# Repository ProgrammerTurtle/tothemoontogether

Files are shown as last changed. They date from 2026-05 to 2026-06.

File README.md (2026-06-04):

# To The Moon Together

## Overview

fulluptmtt1

To The Moon Together, or TTMT, is a 6 foot tall, 3” diameter, N-Class sub minimum diameter amateur sounding rocket - meaning a rocket carrying scientific payloads. N-Class being the motor class, and sub minimum diameter meaning that the motor casing is the main structure of the rocket - no additional body tube around it. This allows for very high performance - aiming for mach 3 and an altitude of 62 thousand feet (19KM).

Current Planned Launch: BALLS 34 in the Black Rock Desert, September 2026. 

## Flight Avionics

TTMT will be flying a MetrumITX and Featherweight Blue Jay inside of the nose cone avionics bay. These two computers are responsible for parachute deployment and flight logging. 

## Payload

The payload features a three-board distributed instrumentation avionics stack using a CAN-FD bus — each board carries its own STM32G0B1CCU6 MCU, enabling redundant cross-validation and independent experiment processing



**Experiment 1** is a Geiger counter: An SBM 21 geiger tube resides at the bottom of the payload for monitoring cosmis ray flux. At 62kft, the rocket should be nearing the Regener-Pfotzer maximum point of cosmic flux.

**Experiment 2** is atmospheric charge measurement: By referencing between the nose tip and rocket body, across the insulating fiberglass, atmospheric gathered static charge can theoretically be monitored during flight.

**Experiment 3** is an attempt to measure air density, and thus altitude, through structure resonance: By utilizing a piezo transducer embedded in the airframe, sine sweeps can be ran on the head end structure during descent. By monitoring resonance response, air density can hopefully be determined. From air density, altitude can be derived. 

To top it all off, there is a Runcam Split 4 v2 camera mounted in a custom shroud and heatsink unit to record footage of the entire flight. Provided the flight is completely nominal, footage of everything from launch to touchdown should be captured. 

That's right, a total of 4 fully custom PCBs. 

fullupttmt2

---

BOM is visible here: https://docs.google.com/spreadsheets/d/1I6cnVDX1UCcmCTm6yOHvnUr30Lxsm3f6hqrUW3u3K9U/edit?usp=sharing
Or attached as a .CSV

## Why am I building this?

For a long time, I have had a passion for rocketry. I started off doing model rockets with my dad and it eventually grew into an obsession with high power rocketry. Whether it's developing machines for producing rocket parts (like a carbon fiber tube winder that I am using for my fin can tube) or actual rockets, I have spent hundreds, if not thousands of hours working on this hobby.
I got an opportunity to do a really high performance build. I was making a camera module for a 3" rocket for a friend and realized - hey, why don't I make a rocket for this camera module too? After all, I have to get a minimum of 2 pcbs assembled per design.
This is that rocket. I have poured so many hours into this, I have almost failed classes over this, I have lost sleep over this. Making it into a scientific platform allows me to merge my passions in rocketry, physics, math, and general science in a way I haven't been able to before.
So. Godspeed!

## PCB Photos and Wiring Diagrams

<details>
  <summary>Click to Expand</summary>

## PCB Photos

### Camera PCB



---

### Instrumentation MCU PCB



---

### Instrumentation Sensor PCB



---

### Instrumentation Geiger PCB



---

### Instrumentation Flex PCB Cables




---

## Wiring Diagrams

### Nosecone AV Bay Wiring


---

### Payload Wiring


</details>

## Zine Page



## This project was made possible by:
- Hackclub: Fallout
- Sunlu 
- And many friends within the amateur rocketry community

## BOM

| Item | Quantity | Cost | Source | Purpose | |
|---|---|---|---|---|---|
| STRUCTURE | | | | | |
| 3" Light Fiberglass Sleeve 20FT | | 1 | $20.00 | https://sollercompositesllc.com/product/natural-uncolored-3in-light-fiberglass-sleeves/ | Nose cone and chute cannon layups |
| Aeropoxy Quart Kit | 1 | $110.00 | https://www.aircraftspruce.com/catalog/pnpages/01-42135.php? | Nose Cone, Chute Cannon, and Fin Can layups | |
| ELECTRONICS | | | | | |
| STLink USB Debugger | 1 | $3.00 | https://www.aliexpress.us/item/3256807639661526.html? | Debugging and Programming Boards | |
| Wio Tracker L1 Pro | 1 | $48.00 | https://www.seeedstudio.com/Wio-Tracker-L1-Pro-p-6454.html | Base Station for Camera Board - Non-custom for Reliability Purposes | |
| LSM6DSO32TR Accelerometer | 1 | $12.00 | https://www.aliexpress.us/item/3256811581419858.html? | Accelerometer - Resonant Response Experiment | |
| MetrumITX Board + Ground Station | 1 | $240.00 | Kev1n8088 on Slack | Tracking, Flight Control | |
| Elvin Beacon | 1 | N/A | Already Owned | Tracking | |
| Reperix Tracker | 1 | N/A | Already Owned | Tracking | |
| Runcam Split 4 V2 Camera | 1 | $90.00 | https://www.aliexpress.us/item/3256808492130639.html? | Recording the awesome flight | |
| 1s 300mah Lipo Battery | 14 | $22.00 | https://www.aliexpress.us/item/3256811737992102.html? | Powering everything - one 1s4p pack + one 1s3p pack + 4 standalone cells + 4 redundant cells | |
| RECOVERY | | | | | |
| Ematches, Firewire MJG | 20 | $20.00 | https://www.csrocketry.com/recovery-supplies/ejection-supplies/firewire-electric-match.html | Recovery Charge Firing | |
| Custom Drogue and Main Parachute | 2 | $140.00 | Parachute Friend | Recovering the rocket - landing | |
| 3/8"" Flat Kevlar | 1 | N/A | Already Owned | Attaching Parachutes to Rocket - Shock Cord | |
| MOTOR | | | | | |
| "3"" Aluminum Tube 6FT | | 1 | $145.00 | https://www.dxengineering.com/parts/dxe-at1317 | Motor Casing Stock, will be cut and drilled to size by Me.  |
| Nozzle Assembly - Aluminum, Phenolic, Graphite  | 1 | $230.00 | Local Machinist | For Motor Nozzle | |
| HARDWARE | | | | | |
| McMaster-Carr Shipping and Tax | 1 | $30.00 | https://www.mcmaster.com | Shipping and Tax | |
| 6-32 1/2" Countersunk Torx Bolt | 10 | $13.00 | https://www.mcmaster.com/90920A148/ | Payload Mounting | |
| 1/4-20 Eye Hanger Bolt | 1 | $18.00 | https://www.mcmaster.com/90172A542/ | Recovery Anchor | |
| M2 Countersunk Torx Screws, M5 | 20 | $8.00 | https://www.mcmaster.com/90236A103/ | Camera Mounting | |
| 2-56 Low Profile Nut | 10 | $5.00 | https://www.mcmaster.com/90730A003/ | Payload Assembly | |
| 2-56 Threaded Rod, 1ft | 1 | $4.00 | https://www.mcmaster.com/90034A460/ | Payload Assembly | |
| 3mm Dowel Pins, 8mm Long | 10 | $10.00 | https://www.mcmaster.com/93600A303/ | Chute Cannon Attachment | |
| 3-48 Socket Head Screws 1/2" Long  | 10 | $6.00 | https://www.mcmaster.com/92185A098/ | Internal Coupler Assembly |
| 3-48 Socket Head Screws 1/4" Long  | 10 | $5.00 | https://www.mcmaster.com/92185A096/ | Internal Coupler Assembly |
|2-56 Button Head Hex Screws  5/16" Long | 20 | $7.00 | https://www.mcmaster.com/92949A078/ | Payload Assemby |
| 1/4' Diameter 5/16" Long Steel Dowel Pins | 20 | $22.00 | https://www.mcmaster.com/98381A535/ | Forward Motor Assembly | |
| 1/4-20 Set Screws, Flat Tip,3/8 | 25 | $7.50 | https://www.mcmaster.com/94355A535/ | Aft Motor Assembly | |
|6-32 Button Head Hex Screw 5/16" | 16 | $5.00 | https://www.mcmaster.com/92949A145/ | Radax Assemblies |
| MISCELLANEOUS | | | | | |
| Purple Mica Pigment | 1 | $14.00 | https://a.co/d/01c2ZzY7 | Coloring Nonmetallic Parts/Accents | |
| Partall Mold Release Wax | 1 | $17.00 | https://a.co/d/0fLlNBUW | Mold Release for Fiberglass/CF part molds. | |
| 915mhz LORA Antenna | 4 | $6.00 | https://www.aliexpress.us/item/3256805050972049.html? | Payload Board Antennas | |
| 500C Thermistor ` | 1 | $10.00 | https://www.aliexpress.us/item/2255800405055939.html? | Nose Tip Temperature Measurements | |
| PCBWay Non-Sponsored Cost | 1 | $25.00 | pcbway.com | PCBWay only offered a fixed amount. | |
| JLCCNC Misc. Cost for Custom PCBS And CNC Parts | 1 | $460.00 | jlccnc.com, fedex.com | OSHWLAB Stars only covers 80% of project cost, so there is a small cost applicable. Shipping through FedEx aswell. | |
| 20mm Piezo Transducer | 1 | $2.00 | https://www.aliexpress.us/item/3256812072131171.html? | Payload Experiment - Resonant Response | |
| SBM-21 Geiger Tube | 1 | $36.00 | https://www.ebay.com/itm/388693213334? | Payload Experiment - Radiation | |
| MMCX RG316 Coax Cable, 10CM | 1 | $3.00 | https://a.aliexpress.com/_mt1c4Fz | Payload Experiment - Atmospheric Charge | |
| MMCX Female to SMA cable , 30cm | 1 | $3.00 | https://a.aliexpress.com/_mL6sZkL | Payload Experiment - Atmospheric Charge | |
| MMCX-KWE Female Right Angle Board Connector | 1 | $3.00 | https://www.aliexpress.us/item/3256807429972438.html? | Payload Experiment - Atmospheric Charge | |
| | | | | | |
| GRAND TOTAL | | $1,799.50 | | | |

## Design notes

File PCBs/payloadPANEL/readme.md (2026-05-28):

This is a panelized form of the three payload PCBs for the purpose of saving money when ordering. Saves almost $100 from JLCPCB! 

No Schematic.

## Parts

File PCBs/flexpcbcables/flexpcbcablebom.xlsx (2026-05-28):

No. | Quantity | Comment | Designator | Footprint | Value | Manufacturer Part | Manufacturer | Supplier Part | Supplier
1 | 4 | 6pinpadtopffc | U1,U1,U2,U2 | 6pinpadtopffc

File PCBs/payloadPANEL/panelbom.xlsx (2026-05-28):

No. | Quantity | Comment | Designator | Footprint | Value | Manufacturer Part | Manufacturer | Supplier Part | Supplier
1 | 1 | 470pF | C1 | C1111 | 470pF | VJ1111D471KXLAT | VISHAY(威世) | C2314698 | LCSC
2 | 3 | 22uF | C2,C54,C55 | C1206 | 22uF | CL31A226KAHNNNE | SAMSUNG(三星) | C12891 | LCSC
3 | 1 | 100pF | C3 | C1206 | 100pF | 1206N101J631CT | Walsin(华新科) | C3866841 | LCSC
4 | 1 | 47uF | C4 | C0805 | 47uF | CL21A476MQYNNNE | SAMSUNG(三星) | C16780 | LCSC
5 | 38 | 100nF | C5,C12,C15,C16,C18,C20,C21,C22,C23,C24,C25,C26,C27,C40,C43,C44,C45,C46,C47,C50,C52,C53,C57,C58,C59,C60,C65,C66,C67,C69,C70,C71,C73,C74,C75,C78,C79,C80 | C0402 | 100nF | CL05B104KO5NNNC | SAMSUNG(三星) | C1525 | LCSC
6 | 2 | 10nF | C6,C51 | C0402 | 10nF | CL05B103KB5NNNC | SAMSUNG(三星) | C15195 | LCSC
7 | 17 | 10uF | C7,C8,C9,C10,C11,C13,C14,C17,C19,C61,C62,C63,C64,C68,C72,C76,C_VBAT1 | C0402 | 10uF | CL05A106MQ5NUNC | SAMSUNG(三星) | C15525 | LCSC
8 | 2 | 4.7uF | C38,C39 | C1206 | 4.7uF | CL31B475KAHNNNE | SAMSUNG(三星) | C1872 | LCSC
9 | 1 | 1uF | C56 | C0402 | 1uF | CL05A105KA5NQNC | SAMSUNG(三星) | C52923 | LCSC
10 | 1 | BAV99 | D1 | SOT-23-3_L2.9-W1.3-P1.90-LS2.4-BR |  | BAV99 | JSMSEMI(杰盛微) | C916421 | LCSC
11 | 1 | BAV20WS-HE3-08 | D2 | SOD-323_L1.8-W1.3-LS2.7-RD |  | BAV20WS-HE3-08 | VISHAY(威世) | C3151637 | LCSC
12 | 1 | SS34 | D3 | SMA_L4.2-W2.7-LS5.0-RD |  | SS34 | JSMSEMI(杰盛微) | C2837271 | LCSC
13 | 1 | UF4007 | D4 | DO-41_BD2.4-L4.7-P8.70-D0.9-RD |  | UF4007 | MDD(辰达半导体) | C960666 | LCSC
14 | 6 | HC-FPC-05-09-6RLTAG | FPC1,FPC2,FPC3,FPC4,FPC5,FPC6 | FPC-SMD_6P-P0.50_HC-FPC-05-09-6RLTAG |  | HC-FPC-05-09-6RLTAG | HCTL(华灿天禄) | C5213748 | LCSC
15 | 3 | M50-3630242 | H1,H2,H3 | HDR-SMD_2P-P1.27_M50-3630242 |  | M50-3630242 | Harwin | C7297891 | LCSC
16 | 6 | B2B-PH-K-S(LF)(SN) | J_BAT1,J_BAT2,J_BAT3,J_NCTIP1,J_PIEZO1,J_PWRSWITCH1 | CONN-TH_B2B-PH-K-S |  | B2B-PH-K-S(LF)(SN) | JST | C131337 | LCSC
17 | 2 | PZ127V-11-04-0720 | J_SWD1,J_SWD2 | HDR-TH_4P-P1.27-V-M |  | PZ127V-11-04-0720 | XFCN(兴飞) | C541879 | LCSC
18 | 1 | TYPE-C-31-M-12 | J_USB1 | USB-C_SMD-TYPE-C-31-M-12_1 |  | TYPE-C-31-M-12 | 韩国韩荣 | C165948 | LCSC
19 | 1 | 22uH | L1 | IND-SMD_L3.2-W2.5 | 22uH | NLV32T-220J-EF | TDK | C295143 | LCSC
20 | 1 | 1uH | L2 | L0603 | 1uH | YL160808-1R0K | YJYCOIN(益嘉源) | C2839970 | LCSC
21 | 1 | 1mH | L3 | IND-SMD_L5.0-W5.0_FNR50XXS | 1mH | FNR5040S102MT | cjiang(长江微电) | C167987 | LCSC
22 | 5 | KT-0805G | LED1,LED2,LED4,LED5,LED6 | LED0805-R-RD |  | KT-0805G | KENTO | C2297 | LCSC
23 | 1 | BSS138LT1G | Q1 | SOT-23-3_L2.9-W1.6-P1.90-LS2.8-BR |  | BSS138LT1G | onsemi(安森美) | C82045 | LCSC
24 | 1 | MPSA42 | Q2 | TO-92-3_L4.8-W3.7-P2.54-R |  | MPSA42 | BLUE ROCKET(蓝箭) | C305411 | LCSC
25 | 1 | FS8205A | Q_BMS1 | SOT-23-6_L2.9-W1.6-P0.95-LS2.8-BR |  | FS8205A | TECH PUBLIC(台舟) | C2830320 | LCSC
26 | 2 | 10MΩ | R1,R17 | R1206 | 10MΩ | KTR18EZPJ106 | ROHM(罗姆) | C2092802 | LCSC
27 | 1 | 200MΩ | R2 | RES-TH_L14.7-W2.54-P10.2-D0.8 | 200MΩ | SM102032006FE | Ohmite | C2641611 | LCSC
28 | 1 | 1MΩ | R3 | R0402 | 1MΩ | FRC0402F1004TS | FOJAN(富捷) | C2909328 | LCSC
29 | 1 | 560kΩ | R4 | R0402 | 560kΩ | 0402WGF5603TCE | UNI-ROYAL(厚声) | C132339 | LCSC
30 | 2 | 100kΩ | R5,R30 | R0402 | 100kΩ | 0402WGF1003TCE | UNI-ROYAL(厚声) | C25741 | LCSC
31 | 2 | 5.1kΩ | R6,R13 | R0402 | 5.1kΩ | 0402WGF5101TCE | UNI-ROYAL(厚声) | C25905 | LCSC
32 | 6 | 10kΩ | R7,R14,R15,R23,R24,R27 | R0402 | 10kΩ | 0402WGF1002TCE | UNI-ROYAL(厚声) | C25744 | LCSC
33 | 4 | 1kΩ | R8,R12,R28,R29 | R0402 | 1kΩ | 0402WGF1001TCE | UNI-ROYAL(厚声) | C11702 | LCSC
34 | 1 | 2kΩ | R9 | R0402 | 2kΩ | 0402WGF2001TCE | UNI-ROYAL(厚声) | C4109 | LCSC
35 | 1 | 330Ω | R10 | R0805 | 330Ω | 0805W8F3300T5E | UNI-ROYAL(厚声) | C17630 | LCSC
36 | 1 | 2.2kΩ | R11 | R0805 | 2.2kΩ | 0805W8F2201T5E | UNI-ROYAL(厚声) | C17520 | LCSC
37 | 1 | 100kΩ | R16 | R1206 | 100kΩ | 1206W4F1003T5E | UNI-ROYAL(厚声) | C17900 | LCSC
38 | 2 | 120Ω | R18,R31 | R0402 | 120Ω | FRC0402F1200TS | FOJAN(富捷) | C2909315 | LCSC
39 | 2 | 120Ω | R19,R32 | R0402 | 120Ω | 0402WGF1200TCE | UNI-ROYAL(厚声) | C25079 | LCSC
40 | 1 | 10kΩ | R20 | R0402 | 10kΩ | FRC0402J103 TS | FOJAN(富捷) | C2906885 | LCSC
41 | 1 | 100Ω | R21 | R0402 | 100Ω | 0402WGF1000TCE | UNI-ROYAL(厚声) | C25076 | LCSC
42 | 1 | 200Ω | R22 | R0603 | 200Ω | 0603WAF2000T5E | UNI-ROYAL(厚声) | C8218 | LCSC
43 | 1 | 51kΩ | R25 | R0805 | 51kΩ | 0805W8F5102T5E | UNI-ROYAL(厚声) | C17737 | LCSC
44 | 1 | 10kΩ | R26 | R0402 | 10kΩ | FRC0402F1002TS | FOJAN(富捷) | C2906861 | LCSC
45 | 1 | 73.2kΩ | R_FB1 | R0402 | 73.2kΩ | 0402WGF7322TCE | UNI-ROYAL(厚声) | C26986 | LCSC
46 | 1 | 470Ω | R_STAT1 | R0402 | 470Ω | FRC0402F4700TS | FOJAN(富捷) | C2909361 | LCSC
47 | 2 | SH-4.5x4.5x4.0H-TP | SW1,SW3 | SW-SMD_4P-SH-4.5X4.5X4.0H-TP |  | SH-4.5x4.5x4.0H-TP | SHOU HAN(首韩) | C52092029 | LCSC
48 | 1 | LMP7721MAX/NOPB | U1 | SOIC-8_L4.9-W3.9-P1.27-LS6.0-BL |  | LMP7721MAX/NOPB | TI(德州仪器) | C2864387 | LCSC
49 | 1 | MCP73831T-2ACI/OT | U2 | SOT-23-5_L3.0-W1.7-P0.95-LS2.8-BL |  | MCP73831T-2ACI/OT | MICROCHIP(美国微芯) | C424093 | LCSC
50 | 1 | TLV3201AIDBVR | U3 | SOT-23-5_L3.0-W1.7-P0.95-LS2.8-BR |  | TLV3201AIDBVR | TI(德州仪器) | C105188 | LCSC
51 | 1 | XC6206P332MR | U4 | SOT-23-3_L3.0-W1.7-P0.95-LS2.9-BR |  | XC6206P332MR | UMW(友台半导体) | C347376 | LCSC
52 | 3 | TCAN1042HVDRQ1 | U5,U7,U8 | SOIC-8_L4.9-W3.9-P1.27-LS6.0-BL |  | TCAN1042HVDRQ1 | TI(德州仪器) | C485807 | LCSC
53 | 1 | BQ29700DSER | U6 | WSON-6_L1.5-W1.5-P0.50-TL |  | BQ29700DSER | TI(德州仪器) | C183096 | LCSC
54 | 1 | TPS61023DRLR | U9 | SOT-563_L1.6-W1.2-P0.50-LS1.6-BR |  | TPS61023DRLR | TI(德州仪器) | C919459 | LCSC
55 | 1 | LSM6DSO32TR | U11 | LGA-14_L3.0-W2.5-P0.50-TL |  | LSM6DSO32TR | ST(意法半导体) | C1864162 | LCSC
56 | 1 | W25Q128JVPIM TR | U12 | WSON-8_L6.0-W5.0-P1.27-BL-EP |  | W25Q128JVPIM TR | Winbond(华邦) | C2441427 | LCSC
57 | 3 | STM32G0B1CEU6 | U13,U16,U18 | UFQFPN-48_L7.0-W7.0-P0.50-BL-EP |  | STM32G0B1CEU6 | ST(意法半导体) | C2829190 | LCSC
58 | 1 | MS560702BA03-50 | U14 | SENSOR-SMD_MS560702BA03-50 |  | MS560702BA03-50 | TE Connectivity(泰科电子) | C97627 | LCSC
59 | 1 | SHT40-AD1F-R2(TOKMAS) | U15 | DFN-4_L1.5-W1.5-P0.80-TL-EP |  | SHT40-AD1F-R2(TOKMAS) | Tokmas(托克马斯) | C54823945 | LCSC
60 | 1 | MT3608 | U17 | SOT-23-6_L2.9-W1.6-P0.95-LS2.8-BL |  | MT3608 | 西安航天民芯 | C84817 | LCSC
61 | 1 | 6GHz | U19 | MMCX-TH_DL-MMCX-KWE | 6GHz | BWMMCX-KWE | BAT WIRELESS(蝙蝠无线) | C5137199 | LCSC
62 | 1 | CH340C | U_USB1 | SOP-16_L10.0-W3.9-P1.27-LS6.0-BL |  | CH340C | WCH(南京沁恒) | C84681 | LCSC
63 | 3 | 8MHz | X1,X2,X3 | OSC-SMD_3P-L3.2-W1.3-P1.20-L | 8MHz | CSTNE8M00GH5C000R0 | muRata(村田) | C341525 | LCSC

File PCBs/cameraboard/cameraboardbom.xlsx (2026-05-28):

No. | Quantity | Comment | Designator | Footprint | Value | Manufacturer Part | Manufacturer | Supplier Part | Supplier
1 | 4 | 10uF | C7,C44,C45,C46 | C0402 | 10uF | CL05A106MQ5NUNC | SAMSUNG(三星) | C15525 | LCSC
2 | 1 | 68pF | C13 | C0402 | 68pF | 0402CG680J500NT | FH(风华) | C190580 | LCSC
3 | 11 | 100nF | C21,C22,C23,C24,C25,C26,C27,C28,C29,C30,C40 | C0402 | 100nF | CL05B104KO5NNNC | SAMSUNG(三星) | C1525 | LCSC
4 | 2 | 1uF | C31,C43 | C0402 | 1uF | CL05A105KA5NQNC | SAMSUNG(三星) | C52923 | LCSC
5 | 1 | 10nF | C33 | C0402 | 10nF | CL05B103KB5NNNC | SAMSUNG(三星) | C15195 | LCSC
6 | 1 | 4.7uF | C34 | C0402 | 4.7uF | CL05A475MP5NRNC | SAMSUNG(三星) | C23733 | LCSC
7 | 2 | 470nF | C35,C36 | C0603 | 470nF | CL10B474KA8NNNC | SAMSUNG(三星) | C1623 | LCSC
8 | 1 | 47nF | C37 | C0402 | 47nF | 0402B473K500NT | FH(风华) | C82219 | LCSC
9 | 2 | 4.7uF | C38,C39 | C1206 | 4.7uF | CL31B475KAHNNNE | SAMSUNG(三星) | C1872 | LCSC
10 | 2 | 22uF | C41,C42 | C1206 | 22uF | CL31A226KAHNNNE | SAMSUNG(三星) | C12891 | LCSC
11 | 1 | BALFHB-WL-05D3 | FL1 | CSPG-8_L2.1-W1.8_BALFHB-WL-03D3 |  | BALFHB-WL-05D3 | ST(意法半导体) | C5350080 | LCSC
12 | 5 | B2B-PH-K-S(LF)(SN) | J_BAT1,J_BAT2,J_BAT3,J_BAT4,J_PWRSWITCH | CONN-TH_B2B-PH-K-S |  | B2B-PH-K-S(LF)(SN) | JST | C131337 | LCSC
13 | 1 | B5B-PH-K-S(LF)(SN) | J_CAM | CONN-TH_B5B-PH-K-S-LF-SN |  | B5B-PH-K-S(LF)(SN) | JST | C157993 | LCSC
14 | 1 | 6GHz | J_RF | IPEX-SMD_BWIPX-1-001E | 6GHz | BWIPX-1-001E | BAT WIRELESS(蝙蝠无线) | C496552 | LCSC
15 | 1 | PZ127V-11-04-0720 | J_SWD | HDR-TH_4P-P1.27-V-M |  | PZ127V-11-04-0720 | XFCN(兴飞) | C541879 | LCSC
16 | 1 | TYPE-C-31-M-12 | J_USB | USB-C_SMD-TYPE-C-31-M-12_1 |  | TYPE-C-31-M-12 | 韩国韩荣 | C165948 | LCSC
17 | 1 | 1uH | L1 | L0603 | 1uH | YL160808-1R0K | YJYCOIN(益嘉源) | C2839970 | LCSC
18 | 3 | KT-0805G | LED4,LED5,LED6 | LED0805-R-RD |  | KT-0805G | KENTO | C2297 | LCSC
19 | 1 | 15uH | L_SMPS | IND-SMD_L2.5-W2.0 | 15uH | XRNR252010-15uH/M | XR(祥如) | C5289261 | LCSC
20 | 1 | FS8205A | Q_BMS | SOT-23-6_L2.9-W1.6-P0.95-LS2.8-BR |  | FS8205A | TECH PUBLIC(台舟) | C2830320 | LCSC
21 | 1 | 10kΩ | R4 | R0402 | 10kΩ | RC0402JR-0710KL | YAGEO(国巨) | C60489 | LCSC
22 | 3 | 10kΩ | R5,R13,R14 | R0402 | 10kΩ | 0402WGF1002TCE | UNI-ROYAL(厚声) | C25744 | LCSC
23 | 2 | 5.1kΩ | R6,R7 | R0402 | 5.1kΩ | 0402WGF5101TCE | UNI-ROYAL(厚声) | C25905 | LCSC
24 | 2 | 1kΩ | R8,R12 | R0402 | 1kΩ | 0402WGF1001TCE | UNI-ROYAL(厚声) | C11702 | LCSC
25 | 1 | 2kΩ | R9 | R0402 | 2kΩ | 0402WGF2001TCE | UNI-ROYAL(厚声) | C4109 | LCSC
26 | 1 | 330Ω | R10 | R0805 | 330Ω | 0805W8F3300T5E | UNI-ROYAL(厚声) | C17630 | LCSC
27 | 1 | 2.2kΩ | R11 | R0805 | 2.2kΩ | 0805W8F2201T5E | UNI-ROYAL(厚声) | C17520 | LCSC
28 | 1 | 100kΩ | R15 | R1206 | 100kΩ | 1206W4F1003T5E | UNI-ROYAL(厚声) | C17900 | LCSC
29 | 1 | 73.2kΩ | R_FB1 | R0402 | 73.2kΩ | 0402WGF7322TCE | UNI-ROYAL(厚声) | C26986 | LCSC
30 | 1 | 470Ω | R_STAT | R0402 | 470Ω | FRC0402F4700TS | FOJAN(富捷) | C2909361 | LCSC
31 | 1 | TS24CA | SW1 | SW-SMD_2P-TS24CA |  | TS24CA | SHOU HAN(首韩) | C393942 | LCSC
32 | 1 | MCP73831T-2ACI/OT | U2 | SOT-23-5_L3.0-W1.7-P0.95-LS2.8-BL |  | MCP73831T-2ACI/OT | MICROCHIP(美国微芯) | C424093 | LCSC
33 | 1 | TPS61023DRLR | U3 | SOT-563_L1.6-W1.2-P0.50-LS1.6-BR |  | TPS61023DRLR | TI(德州仪器) | C919459 | LCSC
34 | 1 | XC6206P332MR | U4 | SOT-23-3_L3.0-W1.7-P0.95-LS2.9-BR |  | XC6206P332MR | UMW(友台半导体) | C347376 | LCSC
35 | 1 | BQ29700DSER | U6 | WSON-6_L1.5-W1.5-P0.50-TL |  | BQ29700DSER | TI(德州仪器) | C183096 | LCSC
36 | 1 | SKY13351-378LF | U7 | DFN-6_L1.0-W1.0-P0.35-BL-EP0.15 |  | SKY13351-378LF | SKYWORKS | C129189 | LCSC
37 | 1 | STM32WLE5CCU6 | U8 | UFQFPN-48_L7.0-W7.0-P0.50-BL-EP5.6 |  | STM32WLE5CCU6 | ST(意法半导体) | C2888218 | LCSC
38 | 1 | CH340C | U_USB | SOP-16_L10.0-W3.9-P1.27-LS6.0-BL |  | CH340C | WCH(南京沁恒) | C84681 | LCSC

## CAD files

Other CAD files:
CAD/fullupTTMT.step
CAD/fullupTTMT.f3z

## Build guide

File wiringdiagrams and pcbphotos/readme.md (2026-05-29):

The wiring diagrams are split into two sections. One is the Nose Cone AV Bay and one is the Scientific Payload. 

The pcb photos are in text files named after their pcb.

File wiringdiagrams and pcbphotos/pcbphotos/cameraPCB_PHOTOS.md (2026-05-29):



cameraboardschematic

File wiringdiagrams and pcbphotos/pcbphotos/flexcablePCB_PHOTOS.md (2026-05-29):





flexcableschematic

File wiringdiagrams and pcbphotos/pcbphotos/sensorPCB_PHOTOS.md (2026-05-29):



sensorboardschematic

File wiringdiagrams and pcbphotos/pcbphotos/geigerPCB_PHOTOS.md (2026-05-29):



geigerboardschematic

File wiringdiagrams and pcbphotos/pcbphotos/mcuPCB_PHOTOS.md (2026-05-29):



cameraboardschematic

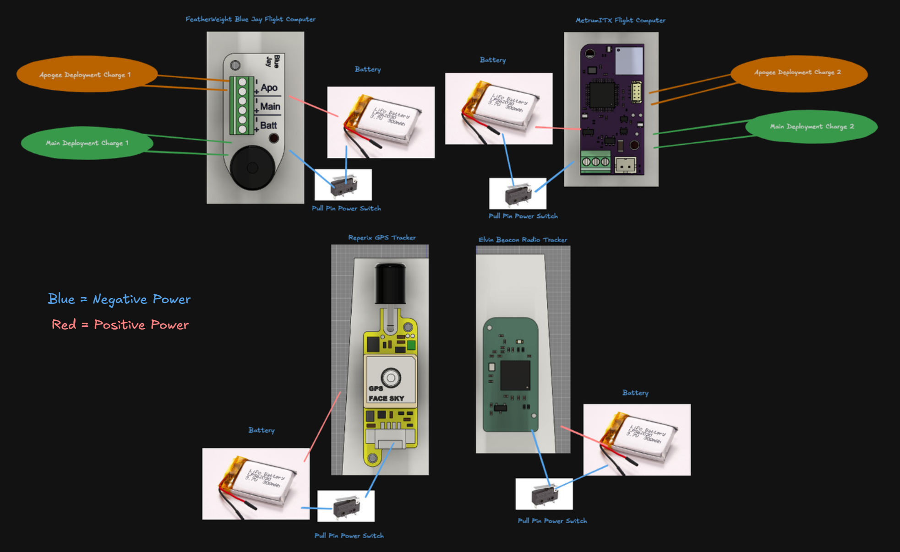
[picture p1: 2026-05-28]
wiringdiagrams and pcbphotos/noseconeavbaywiring.png

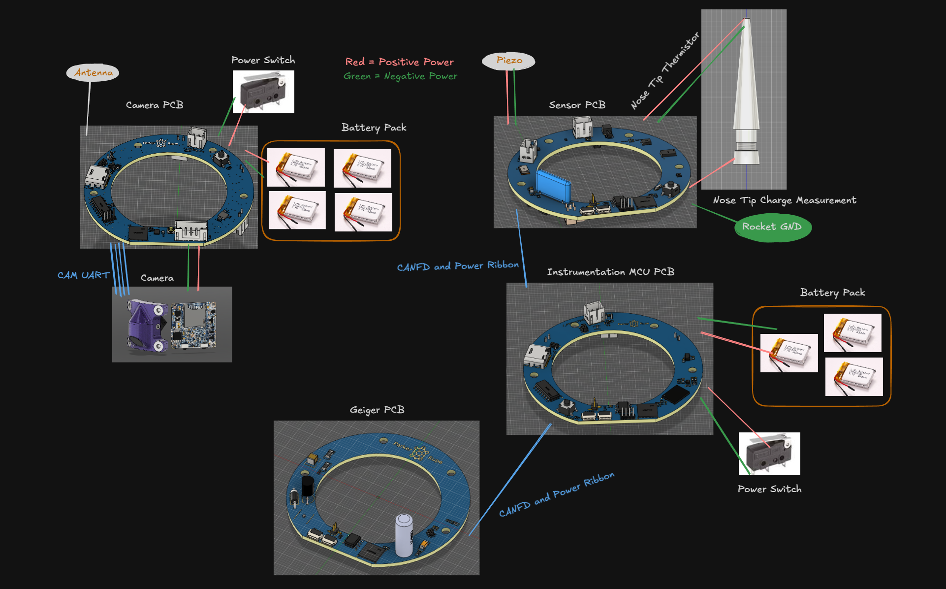
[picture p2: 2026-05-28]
wiringdiagrams and pcbphotos/payloadwiring.png

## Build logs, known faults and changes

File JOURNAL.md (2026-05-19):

# 5/18/2026 8pm - Partial BOM, renders, make a nice readme.
_Time Spent: 3h_

Alright, heres the logistics stuff I was talking about. Basically everything I need to do for grant submission and ordering - the final steps before building. 
First, I wrote up a partial BOM. This thing got expensive so quick - I don't think hackclub will be paying for propellant anymore. Which is fine, that was kinda a maybe already and was going to be tedious af. I can get a job before launch. 



See. Man, is it spendy. All I have left are some little o rings and other doodads I need to hear back on my prop friend on, plus anything I may have forgotten already. I seperated it out into section and colored it and everything, its so nice. I am trying to get two commercial flight computers for this - we will see how that goes. If they complain I can show how its significantly cheaper than any other equivelants and we will see what happens. I think the point of burnout is that its fine though?

Anywho, next was renders. I do all my renders with the native fusion tools - this time I used an actual environment though instead of my usual grey background. It turned out pretty cool and helps a lot with depth!





There are no background versions of the exact same renders present in my README. Speaking of, I made that! I typed up some nonsense to make it sound cool, copy and pasted a lot from my OSHWLabs and burnout pitch, etc. until I was relatively happy with it. It does feel a little empty but that just be how it be sometimes. Maybe I could yap more about the PCBs? I really don't want to tho. Here's what that looks like: 







Ain't it nice! I kinda have a consistent format between all my readmes and it seems to work well. If it ain't broken, why fix it? 

All that's left now is final logisitics and submitting. Yippee!!!

# 5/18/2026 2pm - I Forgot Drawings and Production Files
_Time Spent: 4h_

As the title says, I forgot drawings and production files. 
Since so many of these parts have threads, I need drawings to call those out. I also need to highlight critical dimensions. 
Initially I was getting all of these parts made by JLCCNC. But, they just increased all of their prices. So, based on a silly offer from a machinist friend of mine, I will likely be getting all my parts made by them. Or at least all of the ones that they can handle. 
Moving on. 

I have 17 custom machined parts in this rocket. Well, 17 individual designs, one of them has a quantity of 4. So 17 designs, 20 parts. 
Almost all of them have threads and thus need a drawing. Some of them don't have threads, but still need drawings for critical dimensions. Such as the graphite and phenolic parts, which are being manufactured by a different friend. 





Here they all are. I'm gonna go through every drawing but you can see them all here. I ended up with 11 drawings. Not awful. 



This is the nose cone radax. It bonds into the base of the nose cone and is how the nose cone attaches, as well as the avionics and recovery. Here I am just calling out threads.



This is the nose tip. It is the very tippity top of the rocket. Here I am just calling out threads and the overall conical profile (so angle, diameters, and length). 



This is the frustrum. It attaches the nose tip to the nose cone and the charge measurement header to the nose tip. Here I am calling out threads and overall important dimensions of the profile.



This is the forward closure. It seals the top of the rocket motor and has an attachment point for a recovery anchor. Here I am calling out the threads for that recovery anchor point and the dimensions of the O-Ring grooves. 



This is the female conical coupler. It couples the head end unit to the rest of the rocket body and is mounted to the top of the rocket motor via a radax joint. Here I am calling out critical dimensions for the coupler + radax joint and the threads. 



This is the nozzle carrier for the motor. It holds the phenolic and graphite sections of the motor nozzle and facilitates a seal with the casing and liner via oring grooves. Here I am calling out critical dimensions of the overall profile such as tapers and diameters, plus the oring grooves. 



This is the avionics sled mount. It attaches the fiberglass avionics sled to the rest of the rocket body. Here I am just calling out the 3 threads for the avionics sled. 



This is the avionics/recovery bulkhead. It is the "centerpoint" of the rocket and attaches the recovery, avionics, and overall headend structure together. Here I am just calling out threads. 



This is the camera module main structure. It acts as heatsinking for the camera board and holds batteries + mounting for the instrumentation setup. Here I am calling out threads to the best of my abilities - it is a really wonky part. 

That's it for all the drawings of the aluminum parts! The last two drawings are graphite and phenolic for the motor. 



This is the graphite throat insert for the nozzle assembly. It resists erosion at temp to allow for more consistent motor performance. It is in imperial, unlike the other drawings, which are metric. This is because of who is producing the parts. Here I am calling out all dimensions as I believe they machine manually. So following a drawing is easiest for them. 



This is the nozzle phenolic insert. It erodes/ablates in a consistent known manner and is a very efficient insulator. It holds the graphite throat and is inserted into the aluminum nozzle carrier. Here I call out all dimensions for the same reasons as above, in imperial. 

That's all the drawings! It took forever to get them done, especially since my wifi was struggling. I had a spreadsheet open the whole time for keeping track of what I was doing. 



You can see that here. With 17 parts, you can't do it mentally anymore. Yay for spreadsheets. 

Not every part needed a drawing as not every part has critical dimensions or threads that need called out besides as simple +- 0.1mm of CAD. Since they are using CNC machining they will be working with the cad so it is ok. There were not many other changes made to the other parts - the retaining rings had the bolt or pin holes removed so I can match drill them physically so they align perfectly with the case - that is the only other change. Nice and simple, get 'er done. I can now continue on with BOM making. 

# 5/17/2026 6pm - Done? AV Bay + Last Touches??
_Time Spent: 5h_

I think I am done with the design... somehow...
Pretty scary thought if I am being honest here. That means I just need to do BOM and logistics for submitting. 

Anywho, what did I do? 
I did:
- AV Bay
- Screws + Pins and General Hardware
- Finalize Motor
- Finalize Sim

Starting with the AV Bay, I decided I will be flying a Featherweight Blue Jay and a Metrum ITX. The blue jay is an ultra compact flight computer from Featherweight Altimeters which is perfect for space efficiency. Metrum ITX is something special - it's a full computer and gps tracker with live telemetry, called the Telemetrum, but scaled down to the size of the blue jay. It is witchcraft and I am excited. 

I am also using a tracker called Reperix and a tracker called the Elvin Beacon. Reperix is an ultra compact GPS tracker from Silicdyne while the elvin beacon is a radio tracker designed by a very cool guy named Elvin. 

Each tracker and each computer gets a 1s 200mah lipo battery. Is that overkill? Yes. Do I care? No. 
I will also likely be getting a magnetic power switch from Featherweight, but that is not modeled due to the inconsequential size/mounting and me not knowing where it will go once everything is wired. It will just be VHB taped in place though so its ok. 



This is the AV assembly. 





It mounts to the same bulkhead that the chute cannon mounts to, using the same screw holes. This then bolts in a 6mm thick fiberglass panel that makes up the AV sled. This is what all the electronics mount to. All the non electronics mounting is 3-48 socket head hardware. Nice and simple. 



I literally just extruded the top of the bulkhead and added mounting tabs for the panel. 



There is something special in the base: The piezo! This is going to be potted (epoxied) into place and then clamped down tight by the screws. Since this is effectively the structural mating point of the whole head end assembly, it is hopefully a good spot to resonate. 



I also threw together a quick frustrum up top for the nose cone tip. This is what hold the nose cone tip into the rocket - it is just a threaded joint. The bore down the middle is for the thermistor. 



You may notice a hole on the bottom face - this is a 2-56 screw hole for attaching the charge measurement coax lead. It will just be a simple crimped terminal bolted on. 

With one last double check of all the head end screws, we get left with this gorgeous cross section: 



All that was left was motor and screw stuff. For motor stuff, I talked a lot with my propellant buddy and decided on an N3250. N being the motor class, 3250 being the average thrust in newtons. This really only affects the cad by having an 0.9" nozzle bore - which I adjusted the cad to show.

Throwing that motor into a sim gives us: 





Pretty solid final performance! Mach 3 and 62k feet. Glorious! 

For screws I just had to add: 



1/4" dowel pins in the forward closure 



And 1/4-20 set screws in the aft closure.

That's it! That's a rocket! 
Godspeed!





Now, I just need to make the BOM and some logistics stuff such as making the repo look nice and taking renders. Oh, and maybe designing part molds? But I may do that post-grant submission since they are just printed by me. 

Not gonna lie, I am terrified of making this BOM. 
Time to get to work gang. 

# 5/14/2026 11pm - Finally, A Cad Entry - Fins and Full Up Model
_Time Spent: 6h_

Things are getting exciting y'all. I was finally able to move back to working on cad and I had two clear goals:
Design coupling to the motor
Design a fin can/fin attachment method. 

So let's get started. 



First thing I did was get motor case CAD from my propellant friend. This is just a starting point with an architecture I know works. 



I started by sketching out the coupler. This was conical, a female version to match the male that is present on my payload/head end module. However, I forgot the attachment!

So. This is going to be yet another RadAx joint, like the one that attaches my nose cone. The lower section of the radax joint will actually be the retaining ring for the upper closure of the rocket motor. This retaining ring will be permenantly pinnned in place via press fit pins for rigidity purposes - there can be zero slop in the coupler. I can simply load the motor from the aft end, which will still be threaded. 



The conical section got revolved so I could then make the radax. Honestly, it had been long enough that I kinda forgot how I did this the first time, so this took a really long time. I had a few necessary constraints though. 
- Minimum 1/8" thickness of all features
- Ample interface distance, at least 1/8" aswell
- Be part of the retaining ring
- Do not extend into the conical coupler at all

With that in mind I got to work on that sketch. this took many revisions and at least an hour but I am not good at taking progress photos. 



The two sections of the radax get revolved and then I add mounting holes. 





After being joined with the retaining ring, it's a pretty cool part. The retaining ring uses 1/4" pins.



Fins!



I simply took the fins I made a while ago and added 18mm fillets that interface with the motor case - because the motor case is the rocket body. 



That gives this pretty cool rocket!

However, it is wrong. The motor case CAD is apparently innacurate. So, we get to make some changes to use the new accurate motor. 



The first step was making a fin can though. This is way simpler than it looks - 2mm thick tube, 1" long taper up front, 18mm fillets. I did cool variable fillets on the tips to get a nice taper. 



My process for making these is pretty straight forward. I create copies of the fins and tube, join them together (first you must press pull the root of the fin so that the root is intersecting the tube), then fillet the root, and subtract the tube and fin body copies. Boom! Fillets that are like 99% accurate to life. The front aluminum taper is just a simple sketch and revolve. 

As for the new motor case, the main change is the solidification of the design details. 1/4" pins, 1/4-20 set screws for the lower closure, and an expansion cone. 







The second photo showcases the nozzle architecture and expansion cone. It goes graphite throat -> phenolic carrier -> aluminum carrier -> aluminum expansion cone. The expansion cone has a lip on the outside for the fin can to sit against. Initially, the fin can was further forward and the lip was not present (well it was, but moved up) like this: 



However, we moved it back for two reasons. One, generally the further back your fins the more stable you are as stability is defined by the distance between your center of mass and center of pressure - moving the fins back moves the center of pressure back, away from the center of mass. Two, having more of the fin can over the nozzle section will be better for the fin can longevity. This is because that will actually be the coldest part of the case due to the sheer amount of material/thermal mass - being higher up risks melting my epoxy. 





Man, she's pretty. This gives us a full-up cad that looks something like... this:





I love it so much. I am proud of it for sure.

So, what's left? 
I need to make:
- The nose cone AV bay, for actual flight control avionics
- Finalize chute cannon design
- CAD Parachute placeholders to verify packing
- Specific motor specifications
- Add ALL the screws and pins
- General logistics

Really, not much at all. I can hopefully get to ordering soon. I am so excited. 

# 5/14/2026 4pm - One More PCB Entry
_Time Spent: 5.5h_

Howdy howdy. I was told that I can save money by paneling the boards. This means combining the three boards that don't have specific stack ups into one like single "board". The camera board needs to stay independent because it has a specific stack up for radio stuff.
So I was initially like OK I'll just stick them all side-by-side. Turns out that doesn't work and you need these like panel tab things.





This was my first attempt. It ended up like filling in the gaps between some of the boards because I didn't config it properly.
So I try again.



I actually managed to make it even worse. So I thought I would need to add mouse bites around the whole board. That won't work though, because it will just ruin the outer dimension which is crucial to it, sliding into a part.

So I talk to a friend who has done this before and they told me I should create a sketch in Fusion that highlights a proper panel outline and add slots instead of board edge for the board themselves with tabs.



This is the example they showed me. 



Initially I made this big mess of board outlines that you see here as a sketch in fusion 360. This wasn't working because that should've been something I realized sooner but outlines need to be continuous otherwise weird stuff happens.





So I made this



And it did this.

Still no. 
turns out you need margins on top of the boards so that the slot is not touching the rails otherwise, it'll just fill in the slot.



So I did that. And it worked! I finally have a working panel board that will save me about 100 bucks which I can put towards CNC parts. Yay.
I went through so many iterations of this panel. I tried just outlines. I tried just slots. I tried adding tabs manually in EasyEDA. I tried manual mouse bites around the full thing. I tried all this stuff and eventually it worked, but it took hours. Was it really worth only 100 bucks? I mean, I hope so.



just to recap, what ended up working? Well I made a sketch of my outline and slots and overall alignment in fusion 360 to start. Easy EDA is surprisingly incompetent at this. I then import that as a DXF into Easy EDA and align my boards. I then annotate all the designators on every component to be unique, align the slots, add margin... and order!



# 5/13/2026 8pm - Finish fixing PCBS, new pcb total.
_Time spent: 4h_

Yes, I do have 3 entries today. I did not get much school work or sleep done. Yippee. 



The last pcb to fix was geiger. This one was really not much work - its a simple board. 
Once again spent a while checking every component for a basic alternative. Turns out nothing rated past 200v is basic availability. Lame. 



So, all that changed was the simple passives, and of course getting everything on the top side. 



Which I pulled off! Like, everything everything. I am pretty proud. 





Now, for the hard parts.

I added everything into the cart and it still totaled $700. WTF?? Turns out...



I selected the wrong flash chip for my MCU board. This one is two hundred dollars. Man. I need the 128mb, not 1G. Easy fix though, and no rerouting.

However, some changes were a bit sadder. The ADXL275 and TMP117 were both $10-$15 each and required standard PCBA. This led to me nerfing the sensor board a bit by removing those so I can have economic pcba. I also have to solder the LSM6 accelerometer myself due to that also being standard only. Soooo.. this will be fun! But it saves hundreds of dollars lol. 



See, tmp117 and adxl275 missing. It was good while it lasted. 



But the total is literally like 60% less now! Thats within the budget posed by oshwlabs. Score.

I do need to account for MCUs though. I need to preorder those and it will add like $10 I think? Which is still fine.
Missing the tmp117 and adxl are honestly no big issue. I can get accelerometer data from the flight controllers and temp data from like 3 of the other sensors, so I have both functions covered. It's just never a bad thing to have too much data - but it is bad to cost too much. So we fixed that. 
With that, my pcbs are like, done? I would like to tally up what is left - spoiler, it's all cad and logistics.
I need to:
Finish chute cannon assembly
Finish fin can
Make conical coupler for head end
Make motor case
Make AV bay
Throw it into one big beautiful cad model! 

Honestly, I can pull this off within a few days, I just have to make a portfolio for my whole school year first. That's chill though. 

I used to have parachutes on that list - now I don't! I am commissioning custom ultra compact chutes from a friend - for no additional cost over the original pitch - and I am so, so excited. They are going to be colors I chose and pack so nicely. I cannot wait. 

That's all for today folks. Get ready for so much cad. SO MUCH CAD. Yay!! 

# 5/13/2026 1pm - CAD Entry!
_Time spent: 4h_

I took a break from pcbs to do some CAD!! I did two things: Assemble the full instrumentation stack and redo the nosecone AV bay bulkhead.

Instrumentation stack: 
The instrumentation stack is comprised of a stack of PCBs, aluminum machined parts, and nonconductive 3D printed spacers. The aluminum acts as shielding, heatsink, or robust structure mounting, while the nonconductive 3D printed parts prevent shorting of the PCBs. And of course, the PCBs do all the cool stuff! Vertically it goes: Camera module, mcu pcb, sensor module, geiger module. This is because the camera module is standalone, so it gets to be an end cap, and the geiger generates high voltage so it needs to be shielded from the other boards by the aluminum mounting. Batteries are also stored in that aluminum. That looks like this:



Pretty cool! 



All the non conductive spacers are white, and are hollowed out like this to allow for space for the components. This was done with a simple offset sketch, extrude, and fillets. 





Looks pretty cool!

The whole stack totals 116mm PCB top to bottom. Nice round number. It will be held together by 4x 2-56 threaded rods, with nuts on the end to compress the entire stack together for rigidity.

The AV bulkhead:

This was a challenge. I need cable passthrough of the bulkhead, so I cannot have it be a threaded joint as that would twist up all the wires. I need a connection between the payload and nose! 
So, I came up with this. 







Overcomplicated, I know. Essentially, there are 8 ribs/tabs on the nose cone RADAX section with 8 matching sections on the bulkhead. This allows the bulkhead to be inserted, twisted, and then bolted with 8x 3-48 bolts. This means the bolts are not seeing recovery forces, the aluminum tabs are, which are way stronger! Hopefully this works. It is pretty overly complex but it looks cool and should not be too hard for JLC to machine. If I was machining this myself I would just remove the thinner flange part and it would be way easier - not that it would be super difficult in the first place. To quote my conversation with my propellant friend, "simply get freaky with a fly cutter". It's a pretty cool assembly!

That's the end of my cad break for now. Ugh. Back to PCB purgatory. 

# 5/13/2026 8am - Redid the Sensor board
_Time spent: 3.5h_

I redid the sensor board this time! It honestly did not go that badly. 
I started with redoing the schematic like the others. As it looks the same as before, I do not have photos. But, every passive got replaced.



You can see that here, post-reorganizing. Every passive is with their respective... active? I'm not sure the terminology here, but their component. There is a lot to reroute. 

I started with completely redoing my charge circuit. Hopefully this is a bit cleaner handling of the fragile signal. 



See how it's more linear with shorter traces? That's good, I think. The big shape is a keepout area for planes and solder mask, as those introduce EMI. There is at least a few MM of space on all sides of the fragile charge. 

From there was just like... the rest of it? This board stayed 6 layer again because there just wasn't a way I could reroute the CAN-FD without using internal layers. And since on a 4 layer the two layers are for gnd and 3v3 planes... I am doomed to 6 layer. But that's ok! I think it's discounted right now. 





The bottom layer is super super empty this time! All I have to solder is the coax connector - I can do that! 



Ground pours for EMI of course, which is especially important with the fragile signals. 



Top side is super super busy, of course with the big obnoxious 200 megaohm resistor. I was told I could use multiple smaller resistors to get basic assembly, but the biggest basic resistor is small enough that I can't actually fit enough of them onto the board. High voltage does funny things to you.

But that means...


Wow! The bottom is so empty! This makes my job way easier and saves me a ton of money. Yippee. 

Next is the last pcb, the Geiger. 

# 5/12/2026 8am - Rerouted the MCU board
_Time spent: 4.25h_

So, I may have told mr bob from easyeda that I would be submitting by the end of Thursday or Friday. This means I need to lock in!
The MCU board was really annoying. I am stuck on 6 layer for this board due to CAN-FD stuff and I think that will unfortunately apply to all boards moving forward.
6 layer isn't the main cost though, extended components and double sided pcba is. So, lets try and fix that.
A lot of the work was in the schematic. 



So, this is the updated schematic. Once again, it looks the same. Ugh. But, I went through every single capacitor,resistor, inductor, etc, and if there was a basic version, I switched to it.
Then I moved to the pcb. Every passive that I replaced needed rerouted - and I replaced all of them. This time they needed to be on the top of the board though. 



These are all the passives I had to reroute to be on the top of the board. It is quite literally all of them.
As always, I started with sorting them out by device, and then started placing on the board.





This is some of the stuff I had to do. Another rainbow! I did get everything onto the top of the board though. 



This is what I managed to pull off! Everything but the 3 battery connectors are on the top side - I call that a win! 



Of course, both top and bottom get ground pours again to minimize EMI. Then, I am done! 



Big busy top allows for...



Super empty bottom! Awesome! This means I can do economic single sided PCBA and save a ton of money. Especially since most of it is standard/basic now, not extended.
Next is the sensor board!

# 5/12/2026 12pm - We too expensive, abort abort fall back
_Time spent: 3.5h_

Okay so I finally got in contact with the oshwlabs people and they said they would not cover more than $500. Ok! Seems like no problem. 



## YOUCH. 

Turns out double sided standard pcba on 6 layer via in pad with mostly extended components is stupidly expensive. I didn't bother with optimizing because I didn't think it would be that bad but man is it that bad. So, we gotta make some changes.
A. I must use single sided economic PCBA. This means optimizing for the second side to be things I am comfortable assembling and having the majority of componenets on one side.
B. Make whatever boards I can 4 layer instead of 6. Some of them can totally be 4 layer.
C. Use mostly basic components, not extended. That means using the JLC parts search for every single component. 
D. Git gud. Not really but I just gotta budget cut wherever possible. No fancy colors, no fancy silkscreen, look into paneling, etc. 

So, I started with revamping the camera pcb. 



This is the revamped schematic. Notice how it looks exactly the same, but with different part names? Yeah. I went through every single component and if it had a basic option listed on https://jlcpcb.com/parts/in-stock-parts then I would use it. Every. Single. Component. This took two hours. 
Even my original 10k resistors were extended! 10k resistors! Are you kidding??

Anywho, from there I had to fix my pcb to use those and have almost everything on one side. Almost every part I changed was just a capacitor or something so it was kinda easy to resolve, just tedious. 
And I tried to get everything on one side. I actually succeeded! The only things not on the bottom side are the battery connectors and 4 capacitors. That's it. 



It does mean I did stuff like this though...



All in the name of one side. I also managed to get it done to 4 layer? It was throwing a fit about my plane zone not being empty so I couldn't delete it, despite it being... a plane zone... which is empty by default... I ended up figuring it out though. 



Tadaaa. Everything on one side (almost everything) of a 4 layer pcb for the camera pcb. 



Can I tell what is going on? No. Can you? No. Will it work? I think so, it matches my schematic. But more importantly it should be way cheaper. 



Look how there is almost nothing on that side! Gorgeous. 



We do not talk about this side. That is all for this entry. 1/4 pcbs fixed. Next entry might actually be a cad entry because I am so sick of pcbs. Maybe. We will see ! Ta ta. 

# 5/11/2026 8am - Routed the entire geiger PCB. 

_Time spent: 4h_

This PCB was actually pretty simple! So, I was able to route the entire pcb in one sitting.



I started with getting everything nice and organized. 400v generator on the left, mcu and CANFD in the center, geiger on the right. Really nothing in the back but that's ok, I will need to route back there. 
First thing I did was CANFD. The connectors get their decoupling capacitors and termination resistor jumper (which will be in place), and the transceiver also gets decoupling caps and some vias. 





From there I moved to the right a smidge to give the mcu its decoupling caps and crystal.



All power inputs get decoupling caps. Non negotiable.



Then I did the 400v circuit!! This is a little long in terms of taken up space but that's just because of the robust components required for high voltage. This is that inductor flyback boost. It doesn't matter how much I shield it and whatnot since I have a big aluminum shield between it and the rest of the module in the form of the battery holder.



Then I did the geiger circuit itself, which is fairly straightforward. Decoupling and a comparator, a few resistors for power management. That's it. 

Last is just connecting everything to the MCU and connecting 400v to the geiger. 









Of course, I have to add my ground pours, logo, and thermal vias for the mcu. 



With that we have a finished geiger counter! 



Doing multi mcu was totally the right choice. It makes wiring these pcbs individually so much simpler and the flex cables so much smaller.

That's it for real pcb design!! I have to do custom flex cables but those barely count.

Do I still hate pcb design? Yeah. Is it a useful skill to have and do I love these specific boards? Also yeah!!!! 

# 5/11/2026 12 AM - Made a "Device" (footprint + symbol), finished schematic.

_Time spent: 1.75h_

Okay so, I figured out that I don't need that big resistor chain, I added an extra zero. 


****

So that is solved. I also changed the second resistor in the divider to 50k, as ST specs that the ADC input impedance be 50k or less, not 100k. And 10k is too low of a voltage in my opinion - I don't trust measuring 0.4v nominal.

From there, I made the SBM21 geiger tube! I started with the symbol. It is a simple rectangle with 2 pins, one anode and one cathode. 



Then, I made the footprint. This is two pads stacked vertically on opposite sides of the board with a press fit hole in the middle for the geiger pin. This should hopefully work. 



The pad is extra large to make ample contact with the casing and so I can potentially solder on the tube. 

I then assigned it a 3D model, which is some random one I found online.
And we get... This !



I think it looks accurate and will work well. 

With that existing, I can finish the schematic! I added a bit of finishing touches to make it look nice. 


Close up of the geiger circuit. 



Full schematic! This one is the "simplest" of them all. But, I am a little spooked by generating high voltage, so it gets to be its own board with nothing else. 
It was really difficult to align the 3D model by the way.

Ok, let's talk about the geiger. 70kft is a really cool altitude to go to - it is the Regener-Pfotzer maximum.

Basically: 
When cosmic rays hit the atmosphere they interact with other partiucles and produce secondary radiation and that can produce tertiary interactions with more radiation and whatnot.
So, as the atmosphere gets thicker you get more interactions and thus more radiation as there are more particles to interact with. But, at some point it gets thick enough to where all the cosmic rays have been absorbed and there arent any interactions at all due to no cosmic rays.
SO
There must be a point that strikes a balance between those two factors, leading to peak radiation. That point is about 60-70k feet AGL - exactly where my rocket is going!

That means there should be some super cool data here. I am so excited.








# 5/10/2026 10 PM - Geiger Tube Circuit + Make More Legible

_Time spent: 3h_

For this entry I wired up almost all of the geiger circuit and worked on maknig my schematic more readable by expanding things out and organizing.

First, the geiger power circuit. Preexisting boost converter modules for 400V do not exist, sadly. So, I need to fashion my own module of sorts. 
This is called a flyback module. 



I will try my best to explain it. 
Essentially, the inductor functions by storing electrical energy in a magnetic field coil. It stores energy very short term in that magnetic field, trying to force it out thorugh the circuit. If this circuit is particularly difficult to force current through, it increases voltage to fight that difficulty. By controlling PWM, we can control that difficulty, allowing for a set voltage.

I uh, may have gotten some things wrong in that photo. 100mohm on r6 is supposed to be 100Mohm, and 100kohm on r7 should be 10kohm. 



LCSC won't stock big resistors like they should, and I don't want to deal with requesting new parts, so after HALF AN HOUR of looking through part options I ended up finding 10Mohm resistors in stock, so we get a nice big chain of those. Guh.

Anyways, there is also the other side of the circuit, the comparator charge counter. 



Basically, the comparator compares (crazy, I know) the voltage coming from the geiger tube to the reference voltage defined by the r11-r12 splitter, about 0.5v. Every spike above 0.5v is a radioactive particle hitting the tube!! Pretty cool. 



That makes the full circuit this beautiful thing, minus the geiger tube of course. I need to figure out how to make footprint stuff in easyeda. But that is a problem for future me (aka me later tonight). Ciao.






# 5/10/2026 7 PM - Begin Geiger Pcb Schematic + Add Jumper Thing to Everything CANFD

_Time spent: 1.75h_

So, I forgot that CANFD needs termination resistors at the ends of the chains. These are 120 ohm resistors that bridge canh to canl, the two lines of the diff pair that is CANFD. However, since I want this platform to be expandable, I need to be able to toggle these. This means the logical way is a jumper that can enable or disable the resistor (passing current through it or not). 







Little something like this. Both the MCU board and Sensor board got one, and the geiger board will have one too. This means in the future I could add more boards by just adjusting jumpers. 
I initially used standard dupont headers, but those are huge, so I switched to the same header style/size as the stlink debug header, 1.27mm pitch. 



Anywho, this is the start of the geiger schematic. Same mcu and CANFD setup as the other two boards, of course, but different peripherals for the geiger.

Specifically, we get an HV boost circuit, a tube circuit, and a pulse detection circuit. That's what the component clouds in the middle are, in order left to right as I stated. 
Turns out, there aren't 400v boost converter chips that already exist - I have to make my own. It is fairly simple with a high voltage transistor, an inductor, a rectifier, and then some capacitors and resistors. Do I know how this circuit works? Not really - I will report back next entry with an explanation. 

The tube circuit is just two resistors and a capacitor to power the tube. This will also have a custom footprint for a through hole connector for the geiger tube but I have yet to make that.

Last is pulse detection, which is just a comparator (compares pulses) and soime more capacitors and resistors. 

And that's it! It may sound simple, but I am working with true high voltage with some current, so it is a little intimidating. 

Next entry should have this schematic finished!






# 5/10/2026 5 AM - Small Architecture Change + Finish Sensor PCB

_Time spent: 2.25h_

Ok so I realized something - every CANFD transceiver needs 5v power. And I don't want to deal with generating 5v on evey board. So, instead of putting vbat and 3v3 on the ribbon cables, I am gonna but 5v and 3v3 on the ribbons. The other boards can generate their power off the 5v with roughly the same stuff as with the vbat so its fine. Is it slightly less efficient? Yeah. Do I care? Not at all.

Moving on from that, I routed everything. It was just hooking all the stuff up to the MCU. Easier said than done. 







Look at this utter nonsense. Big round traces all over, so many via in pad. I am scared of the cost of all these PCBs. Regardless, it was actually kinda straightforward? I wired i2c, interrupts, SWD debug, and boot0 switch, and I was done. Oh and 5v power. Forgot that initially and had to redo some stuff. Mainly just the i2c wires so they weren't in the way.

I tried really hard to not route anything near the charge measurement. I ended up routing 5v past it, keeping it as close to the edge of the board as possible (thus as far from the charge measurement as possible). There's no data on this line, just continuous 5v charge, so I think that is less EMI? Because no switching? I am not totally sure but that makes sense to me mentally. 

I also ended up forgetting the thermal vias initially for the MCU? But that was a super easy fix. 

To help with EMI I then did top and bottom ground pours, and I was done! 







You can tell it is done by the presence of my logo, as always. 



That's 3/4 PCBS done. Next is the final pcb - the geiger counter! I am kinda excited for this one because I get to generate high voltage. I do have to make my own footprints for the first time though... 

So close to being done with the pcbs.









# 5/10/2026 4 AM - Routing - Sensor Edition !

_Time spent: 6.333333333333333h_

Hello.
I routed a lot of the sensor pcb. 



Funny how I keep cramming more and more into these boards. 
See that big bar on the left? That's a resistor. Man.


 
Just utter despair. Its twice the width of the MCU. 
Anywho, I began with sorting and arranging as per usual, which you can see in the first photo. The very first thing I then route is the charge circuit - this is super finnicky so it gets priority. High impedance makes data sensitive. 
Anywho I have to do some silliness for routing this, like removing solder mask and applying a guard ring, which is a bare copper trace that circles the circuit. 

So this:



Becomes:



Which then becomes: 






The guard ring and solder mask removal only circles the high impedance/voltage parts of the circuit, and nothing more. This looks a bit wonky, but it should work. Routing the circuit was somewhat straightforward but tedious and time consuming, I just tried my best to minimize the length of all high impedance or high voltage lines. By high impedance I mean literal gigaohms. Finger oils on the board are enough to screw up my data. 

Next was wiring each little sensor up with their power, decoupling, and I2C wiring. All sensors are just wired in parallel on the I2C bus. 

We have: 


The adxl375 Broad Accelerometer


The LSM6 Fine Accelerometer


The TMP117 Thermistor


The MS5607 Barometer


And the SHT40 Humidity + Temp sensor. 

This all gets wired onto I2C via an internal layer. 



I also wired up the piezo drive circuit, with 12v power.
So this: 



Gives 


U17 generates 12v off of a 5v input from the ribbon cables. This then gets fed into a mosfet that is controlled by an mcu pin. The switching of this mosfet through the piezo is what generates the resonance. 

Last for this entry is getting the mcu and CANFD stuff all organized, which looks identical to the MCU board. 



Tadaaaa. 



What's left? Well, I need to wire CANFD and the MCU, including wiring the i2c and whatnot to the MCU. That's it! Then I can move on to the last pcb, the Geiger.



















# 5/9/2026 7 PM - Wired Schematic

_Time spent: 3.75h_

I decided to finish the whole schematic in one sitting.

You know, the more of these I make, the faster I get at doing it. Anywho. 
I started with wiring up a 12v boost converter circuit for my piezo system. Running 12v allows for much stronger actuation. 



The datasheet specifies between 4.7uh and 22uh for the inductor. Because I am running low load, 22uh should be more efficient. 
As for the resistor divider selection, r7 and r8, we have this equation: V_out = 0.6V × (1 + R_upper/R_lower)
With 0.6V being referenece, R7 being upper, and R8 being lower. If R8 is 10k then we can solve this equation for 12v, giving R7 = 190K. I round to 200k since it is a standard size and 12.6v is close enough to be fine. 

Next of course would be the piezo driver circuit. This uses a high speed switching mosfet to turn power rapidly on and off to the piezo. 12v power. 



PIEZO_CTRL is an MCU pin, specifically PA8 as that is the timer output pin. 

From there it is just giving i2c and power to all the sensors, as well as interrupt gpio pins for those who need it. 


MS5607 barometer.


SHT40 humidity and temp. 


ADXL375 broad accelerometer.


LSM6 fine detail accelerometer.


And then two thermistors, tmp117 and dyze design 500c cartridge, for accurate temp. 

Each sensor gets an i2c bus decided by their cs pin, or add0, or csb, or sdo, all the same. 

MS5607 — CSB pin sets 0x76
BMP390 — SDO pin sets 0x77
SHT40 — fixed 0x44
TMP117 — ADD0 pin sets 0x48
LSM6DSO32 — SDO/SA0 sets 0x6A
ADXL375 — ALT ADDRESS pin sets 0x1D

And with that, we have a finished schematic! I have so many tabs open of datasheets, this took a while.


Next is routing this bad boy!










# 5/9/2026 4 AM - Sensor Board - Select Hardware, Begin Wiring Schematic

_Time spent: 3.5h_

Okay so. 

I started with selecting the needed hardware for the charge measurement system. This is potentially handling hundreds of volts, so it needs to be pretty robust. 
I know I want to use coax cabling for the wiring to the nose tip, for shielding. So that means I start with an MMCX connector, a type of coax connector. I chose a right angle through hole one. 
From there I chose the values for my resistor divider.
The resistor divider serves to lower the voltages to something the amp, and thus mcu, can handle. In this case I am aiming for around 3 volts since I am on a 3v3 system. Assuming a peak of 600v for the reading, we get:
Vout=600×1/201≈2.99V
I thus chose 1Mohm and 200Mohm. Yes, mega ohms. The 200Mohm resistor is 15mm long. 

Next was the amp! I chose an lmp7721 because it is cheap, 3v3, and came up first. That's all. 
I also have a BAV99 diode pair for overcurrent and undercurrent protection. This is crucial because atmopsheric static EMI is genuinely crazy and I can't have my board frying. So if voltage spikes like crazy it gets dumped to 3v3 and if it drops like crazy it gets settled to ground.



With some decoupling and filtering we get this circuit. Hopefully it works. It will be super fragile - like, susceptible to finger oils.

Next was general sensoring. I chose:
An adxl375 for high G force readings, up to 200g. It is a cheap option that supports this.
A TMP117 thermistor for precise easy to read temperature.
An MS5607 for barometric pressure and temp. I chose this because I saw that the KATE avionics system, a commercial computer designed for spaceshot rockets, uses it for baro pressure. This is for altitude estimation.
An SHT40 for humidity and more temp because humidity at 70kft is interesting to me - is there any?
And a dyze design 500c cartridge thermistor in the nose tip.

A bit more specialized, I have a mosfet and lsm6dso32tr for piezo vibration control and reading (the LSM is a very accurate accelerometer but lower g force). This is for my experimental attempt to derive air pressure and altitude from structural resonance response. Aka, shake the rocket and read it. 

The charge circuit is the only thing wired for now. Besides the connector for the nosetip thermistor but that doesn't really count. 



That makes this the current state of the schematic. I just need to wire it and then I can do routing!




# 5/6/2026 3 AM - De-Squiggle and Set Up Next Board

_Time spent: 0.6666666666666666h_



Let's just say my board was squiggly. 





But now it isn't! I made all of it smoother. My brother insisted I should. 

Anywho, new document.



We copy over applicable schematics already made in the MCU board. That would be debug stuff, mcu stuff, and CANFD stuff. Everything else will need to be different.
I am getting so excited. Maybe this could be done pcb wise by end of week??
Well I am going on a school trip so probably not but still. 



This feels so proper. I love it. 
Anyways, logistics.

We have: One analog charge input, three thermistor temperature inputs, one humidity input, one barometric pressure/altitude input, one accelerometer input, and one piezo output. I will need to think about piezo and accelerometer coupling to the module to get good readings. Maybe I put them on seperate connectors and bond them to somewhere on the coupler? maybe somewhere at the bottom? I am not sure. I could have like a bottom plate that rigidly compresses the coupler with the whole module and bond the piezo and accelerometer to that plate. Maybe? Idk. I will think on it.

Over halfway on pcbs now.







# 5/6/2026 3 AM - Finish MCU Board Routing

_Time spent: 4.666666666666667h_

Hi! I made pretty short work of this pcb to be honest. Now that I kinda know what I am doing, it goes way faster.



I started with doing my battery charging circuit. Having 4 entire layers I can route on makes this so easy. My battery pack routing (1s3p) went on an inner layer while the charger itself went on the top and bottom layers.

I have a dedicated charging IC, a BMS, and a mosfet pair for the BMS. This allows the batteries to be charged via the USBC port. But - it also prevents overcharge and overdraw, cutting power with the mosfets and either slowly leeching power until it is within the safe limit or keeping all power off until you plug it in. 



You can see the battery pack wiring highlighted in green here. 

From there, 



I did my 5v boost circuit. 



Having done this before on my other board made this fairly straightforward, but it was a little cleaner organized this time. Basically, VBAT goes in with two decoupling caps. The enable pin is pulled to VBAT so that the boost turns on. It then forms a loop of the inductor with VIN, aka VBAT. This is what actually changes the power, I believe. 
The two resistors, FB1 and FB2 decide voltage. This setup should work for 5v exactly unless I screwed it up. Then we get VOUT 5v, which goes through 2 more decoupling caps and then a power LED for debug purposes. Tada, 5v from whatever input is currently coming from the batteries. 

Next was wiring up the CAN stuff fully, as well as BOOT and flash. They were all right next to each other so I kinda had to do them together to make routing work. 



Basically, flash has three lines going to the mcu. One for talking, one for listening, and one for telling the flash chip which of those to do. Pretty simple!

Then, CAN has three lines going to the mcu aswell. One for talking, one for listening, and... one for telling the module which of those to do. Sounds familiar, it's almost like both are just handling data transfer in seperate formats. 
There's just 3 outputs versus 1. Well, also 3 inputs. The MCU and the two CAN connectors, which are connected to eachother for daisy chaining. The cool thing about CAN is you run all the data on the same two "wires", I just also have gnd and power common rails for all three boards. So you just tap into those two by routing it through two connectors on your board, one into the other. It uses the differential between the two wires to determine data.
This board is in the middle, so it gets no termination resistors. 

With that, I just had to put on the finishing touches for wiring the newly generated power and then double checking everything is going into the MCU. Oh, and making sure everything had decoupling caps, because once again I was missing a few. 



Boom, MCU/data central pcb. Now featuring a logo - that's how you know it's done.








# 5/6/2026 1 AM - Routing! And I forgot something

_Time spent: 2.25h_

Okay so. I forgot decoupling for the MCU power input. I also need vbat on the ribbon cables. 



This solves the latter



And this solves the former!

Anywho, I began the pcb. This one is technically denser than the others, but the circuitry itself is simpler due to the lack of RF. Anywho, we start with copying the board outline and starting to sort everything and lay it out.



You can see here some of my clouds of capacitors and resistors. I think they're called passives? Not sure to be honest.

We have mcu and CANFD stuff at the flat side of the board, same as the other. Going clockwise from there is BOOT switch, usb to serial, usb, battery/battery charging/power switch, 3v and 5v stuff, and then the flash storage! 

From there I started working on the simple circuits. Due to sheer density this once again is a 6 layer pcb with VIA in pad. Ouchie my budget. 



LDO goes first. This makes 3v. 



Then flash memory power and decoupling, since it was right there. 



And usbc power and decoupling. 

Last for this entry is the ch340c power and decoupling! 


I like to do power first, if you couldn't tell. Anywho, lets talk logistics. 

Basically, this 6 layer pcb has outer sig on both top and bottom, then two planes of 3v3 and gnd, and then two internal sig planes. One of those internal sig planes may become a vbat plane pending how much I use internal sig. 
This all allows for super nice density through via in pad - but it isn't cheap. Thankfully, I am paying for 80% of the machined and pcb parts through easyeda's OSHWLABS program. This is a program made to support teens in making cool tech through JLC services. 
And I am using it. Yay.









# 5/5/2026 11 PM - Finishing MCU Board Schematic

_Time spent: 2h_

Alright. All I did was figure out MCU pins and put polishing onto the schematic.

So, lots of datasheet reading.



Basically, after a lot of reading, I determined that the mcu doesn't actually have a power circuit and just takes 3v3. Man, I sure spent a lot of time trying to find a power circuit that doesn't exist...

Anyways. 
Pins VBAT, VREF+, and VDD get 3v3 in. VSS and EP get GND. 
SPI_SCK, FLASH_CS, SPI1_MISO, and SPI1_MOSI are all for the flash memory. STB, CANFD_TX, and CANFD_RX are for my CANFD setup! 
BOOT0, SWD_IO, and SWD_CLK (on BOOT0 switch) are for debug. Bootloader and STLINK stuff.
U_USB_D+ and U_USB_D- are for one method of accessing the mcu over usb - the CH340C_TX and CH340C_RX are the other method. One for the stm32's like, firmware stuff, and one for software level, with ch340c being the former. 

Did you know that the stm32 has specific pins for usb and canfd and you can't just give them any gpio? I did not. But now I do! 

I think that is all! Now I can move onto routing. 

SCH_MCUBoardSchematic_1-P1_2026-05-05

Looks good!!!!




# 5/5/2026 6 PM - Filling Dead Space - Redesign

_Time spent: 3h_

Alright howdy.
So, I came up with a way to fill space on the boards - multi mcu CAN FD. 

CAN FD is a two wire communication protocol for talking between boards. It doesn't have to be multi mcu - but in this case it is. I switched to a new mcu. 
STM32G0B1CCU6. This is a neat chip that supports both CAN FD and usb natively. I just need a CAN transceiver to handle signals physically. 
This means each board gets one of these MCUs, one transceiver, and two 6 pin ribbon cable connectors for daisy chaining boards. I can daisy chain boards now! 



I started with the CAN. The left has two FFC ribbon connectors with identical pinouts: GND, CANH, GND, CANL, GND, 3v3. Normally you would just use twisted pairs of normal wire for CAN and that handles all the shielding. But, I don't have space for that. So I will be getting flex pcb ribbon cables with those gnd lines stitched to EMI shielding tape on both sides of the cable. This creates that same faraday cage concept mentioned in a previous entry, but for my CAN signals. 3v3 is there to power the other 2 boards. 



From there I brought back my USB to serial stuff. Since I am using CAN I now have way more available GPIO, so there is no real reason not to have it. I just changed the V3 to be a capacitor straight to ground rather than connecting to 3v3 - turns out, that is an output, not an input, and it is less than 3v, so I can't put it to the net. ?But I am also not using it at all, so it just gets to go to ground. 



And then we have the fancy new MCU! This is not fully wired yet as I still need to do its power circuitry (it needs 1.1v, but it has a way to generate that). But I am just piping all the gpio and whatnot into it.

Oh, fun fact, STLINK CLK and BOOT0 share the same pin here. Really weird. 



So I had to do this to my power switch, adding swd_clk. Since the boot0 condition is only applicable during initial bootup, once it makes it through bootup it switches over to only reading for SWD, which it has. 

I am really excited for the multi mcu can stuff. I did a lot of research into it - this allows for near infinite expansion of my instrumentation stack by just adding more pcbs (and eventually more batteries). The actual limit is somewhere in the 100s, which is infinite for my uses. I love it. And the daisy chained ribbons will look so cool!

Oh, I do need to add jumper availability for 120 ohm CAN termination resistors. I'll do that next entry. Basically, at either end of my CAN path (so first and last pcb) I add a 120 ohm resistor between the CAN wires to terminate it. 
Adios amigos.






# 5/5/2026 5 AM - MCU Board, The rest of it I guess

_Time spent: 2.75h_

So I guess I finished off the instrumentation MCU board? It took a lot less time than I thought it would.
I would like to say, most of the time spent was scouring datasheets to figure out pins. 
I guess this mcu has some 'interesting' documentation when it comes to the pinout so I had to read some forums to figure out what I can actually use the pins for.

But first I needed pins! All of them come from either the usbc port, the sensor board, or the geiger board. Or the flash memory I guess. First I did the connectors to the other boards:



One 12 pin ribbon connector and one 4 pin ribbon connector. The cool ones, with the locking levers. 

I made a nice little table in google docs to keep track of the pins: 



This is part of a 10-page design document I am using to keep track of everything. That's right, 10 pages. Bleh. 

Anyways next was flash memory. And sticking everything into the mcu. 



It basically just has a conversation with the chip using gpio. But like, really fast. And with supplemental power (energy drink?). 

Anywho, that's a board! 



It feels barren and I don't like that. I am actively looking for other things I could put on this board to fill the space - we will see what happens. 

You may notice I got rid of the CH340C usb to serial converter. Turns out, I don't have enough pins for it. But, I can set up a USB bootloader and still do usb programming of the mcu. This mcu has built in usb protocols! The mcu on my camera pcb does not.
I still need stlink for initial programming though. 

Oh shoot I forgot the status led! 



Simple addition, will be very useful for debugging. 

That's it. Hopefully I can figure out something to use up the free space. Auf Wiedersehen.







# 5/4/2026 8 PM - Instrumentation MCU Board

_Time spent: 4h_

Okay, I started the schematic for the instrumentation MCU board. First thing, I decided on using the stm32l412kbu6.



How did I decide on this? Well, I saw that the stm32l4 series has built in USB, very low power draw, and good IO. So, I looked for the most compact option with enough processing power and IO - so I came up with this one. Tada, I spent 45 minutes looking through datasheets and comparing. 

Anyways, Once I had that, I started copying over things I would need for this new pcb that I already made. 



Battery charging/management, 3v3, debug, and usbc/usb to serial. Yes, another battery charging circuit. The rest of the instrumentation is fully independent from the camera, including power wise, for redundancy sake. So it get's its own circuit, but with only 3 cells instead of 4, as it both needs less power and needs more space for the geiger tube. 

After getting that all situated and hooking up the pins to the MCU, I started on connector selection.

I know I want to use JLC flex PCBs as ribbon cables - but how many do I need? 
Turns out, 2. One twelve pin for the sensor board and one 4 pin for the geiger board. I also need a 2 pin jst ph for the nosetip thermistor, for which I am getting a 500c Dyze Design cartridge thermistor rather than a thermocoouple. Thermocouples are too sensitive to interference. Anywho. 



Connectors on the bottom left! 

Oh also. I was gonna do micro sd card storage but it actually doesn't fit. So, we get 1Gbit flash. Yes, 1Gbit. That's 40 minutes of 50kb/s data - hopefully enough for full ascent and descent. I calculated my data usage at 48kb/s:
Geiger counter with a max of 39,000cpm, 500hz-5khz sin sweeps on a piezo with accelerometer reading, humidity, temperature, barometric altitiude, and 500-1khz voltage recordings for atmospheric charge.

There's a LOT of data. 
I already don't have much left on this schematic - just MCU wiring! Oh and like data processing stuff. I might need hardware buffers? I am not sure.

I worked on this off and on for most of my school day, since normal classes have ended for the year.





# 5/4/2026 5 PM - Fix pcb mounting + integrate into CAD + add power switch, done !

_Time spent: 4h_

Alright so. Turns out my mounting holes were a bit in the wrong place. But, it was an easy fix by measuring the displacement in fusion and using the "offset" tool. 
I then brought it into cad finally and got these cool photos. 







It looks great! 

I do have to add the power switch though. I am just adding another JST connector so that the switch can be routed elsewhere into pull pin clusters - basically, you can put multiple power switches on one long pull pin (since each computer gets its own power switch, you have more than 1).



So that switch goes on the VBAT line, cutting off the circuit. 





You can see it on the left there. Looks good! 

With that, the camera module is actually done. Finally. Now, on to the next pcbs. First will be instrumentation MCU + battery charging + sd card logging.








# 5/4/2026 8 AM - jlc does not support buried via

_Time spent: 0.5h_

Oooops
That sucks lol. 

They all go all the way through now tadaaaaaaa. 
I also made some tweaks for ordering, such as double checking bom and no place components and all that jazz. Checked prices and the boards are...



Better than I expected!! Add $40 ish for mcus because I have to preorder them. That's 5pcbs, 2 assembled.




# 5/4/2026 8 AM - PCB done i guess?

_Time spent: 2.5h_

I couldn't sleep so I decided to just get 'er done. 



I did the 3v3 circuit which is just an LDO. 



And I did all the MCU resistors 



And the mcu built in power circuit, an SMPS, hence the inductor. 



Follows this. 

And then I did ground pours on layers 1 and 2 for RF and stitched them with vias to the ground pours one layer below, once again faraday cage. 



Little something like this!

Oh I still have to add the power switch but I cannot do that until he responds, but its an easy add.

Here it is! 





Looks good.









# 5/4/2026 6 AM - Routing Day !!

_Time spent: 6h_

Howdy howdy. I decided to route today. I haven't finished yet but I did make a lot of progress.

So, I started with my layers. I am doing 6 layer double sided pcba with via in pad. Bleh, lots of words. It is not gonna be cheap. 

I started by setting up my layers. We have top sig, ground, vbat/3v3 split, v5_cam/sig, ground, and bottom sig, in that order. Vbat/3v3 split and the grounds are all planes. GND planes were done automatically, I had to do the vbat/3v3 split though. It took a few tries. 









Turns out I needed exclusion zones. Anyways, next I did mcu RF. 







So, it was actually fairly simple. I wired the mcu to the ipd following this: 



Then wired the ipd to the antenna. One gets terminated with a 50 ohm resistor and one gets to go to sig, with the path tuned to be 50ohm using an easyeda calculator. 



It also gives me the specific stackup I need for my pcb layers, which I just specificy when ordering I guess.

I ended up removing all vias to the left of the mcu, which I gave a photo of already, but that didn't happen for a bit so these next few photos won't shiw that. 



From there I did battery wiring. VBAT and V- all get connected together. 

And then that goes into the battery charging circuit! 



So following this... 



We get this! I think. I just connected all the ratwire things and double checked the schematic. I had to move a bbunch of the names because it was crowded so idk. It's a mess. But, it should work. Charging and overdraw protection. 

Next I did the USBC port since it was right there. It needs wired into a serial converter for the mcu. 



This gives...



This! Which is actually still kinda labeled so you can follow it. Mostly, power goes to the serial converter and battery charging circuit, data d+ and d- goes to the serial converter and on to the mcu. That's it, once you add resistors and capacitors. I also wired the swd debug in the process since it was simple. That's just STLINK. 

Next was the camera power circuit. 



This gives uhh...



Honestly this is the most egregious yet because it is on the reverse of the boot button. Let me see if I can... 



Sure why not. So, vbat goes into the boost, and the output (5v) goes into the plug for the camera. The enable pin is being pulled low by the mcu upon boot. Once booted, the mcu pulls the camera down to gnd upon boot, and once the camera needs to turn on, it releases that pulldown and the enable pin drives high. Boom, we are on and will not turn off, even when mcu loses power. This means we can run the camera longer than the mcu can be powered for, squeezing out extra life. 

Huh, I just realized. There's... nothing preventing the camera turning on once batteries are hooked up... huh. 
I should add a power switch. Maybe a pullpin? I will dm the person this is for. I am glad I realized that.

Moving on from that... ugh. I am dumb for not realizing that sooner. 

I connected all the necessary pins from what we wired so far into the MCU and that is all for today lol. Current state of the pcb: 







The holes and stuff around the RF is all trying to shield it from any nearby currents at all. There is a ground pour on that layer and the layer below it, with the holes cutting it off at the sides. AKA, faraday cage with one exit, the ipex connector. Good. 

This will not take much more to finish, I don't think. But, I have been planning 3 more pcbs and a full instrumentation stack. We can talk about that next entry. I am tired and have been staring at this for too long. Night.






















# 5/3/2026 6 AM - Finalize Schematic, then begin Sims

_Time spent: 3h_

Alright. I added an IPD specified by STM for 4 layer pcbs on 18dbm low power 915mhz LORA. I am actually using 6 layers, but they do not have an IPD for that so I picked the closest one and will adjust my pcb to hopefully be fine. From there I could finally wire it all, and the schematic is done. 



FL1 is the IPD, aka filtering and signal management for RF. 



Look how nice it is! Now I can focus on routing (or maybe the schematic of another pcb...).

Except I decided to do sims. I got a motor file from my friend, an N3400, and off we go. 



I made the sim in OpenRocket, an open source and free rocketry simulator. It is literally just the head end I have been developing, plus the fins I developed, plus a motor case. Oh and an expansion cone which is the thing at the far right. Basically a nozzle extension, it allows more performance... somehow? I will read up on it and explain to yall next entry. But I believe it has to do with the amount of air being accelerated increasing. 

Anywho, it is simming 62kft and mach 3.8 launching at BALLS, a launch every fall in the Black Rock Desert.
Openrocket cannot however properly handle supersonic conditions, edge case high performance, and expansion cone performace gains, three things I have. So, I move to RASAero II. 



Cool looking view of the rocket honestly. 



And a much nicer sim accounting for nozzle expansion. Mach 3 and 70kft. Perfect. 

Oh, also, 80 G of accel off the pad, which is going to be so cool. Nyeoooowm. 

That's all for today folks. PCB routing work soon.






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

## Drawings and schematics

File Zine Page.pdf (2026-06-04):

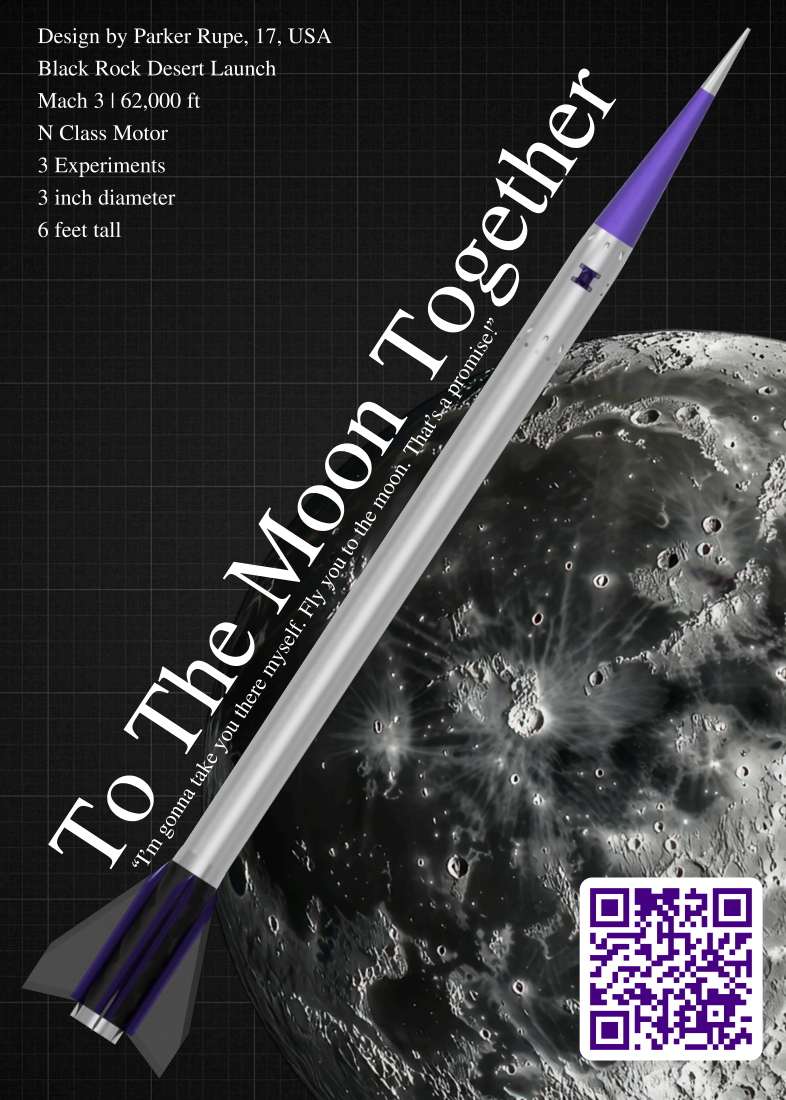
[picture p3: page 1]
N Class Motor; 3 Experiments; 3 inch diameter; 6 feet tall

Design by Parker Rupe, 17, USA

Black Rock Desert Launch
Mach 3 | 62,000 ft

To The Moon Together “I’m gonna take you there myself. Fly you to the moon. That’s a promise!”

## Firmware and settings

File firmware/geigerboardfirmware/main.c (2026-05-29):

/* Geiger Board Firmware — Ring PCB C
 * STM32G0B1CCT6
 * Placeholder firmware for hardware bring-up
 *
 * Peripherals:
 *   - FDCAN1:  CAN-FD bus, 500kbps arbitration / 2Mbps data
 *              This board is END OF BUS — 120Ω termination resistor fitted
 *   - TIM1:    CH1 PA8 — HV boost PWM ~30kHz drives MPSA42
 *   - TIM2:    CH1 PA0 — Input capture, Geiger pulse timestamps
 *   - ADC1:    PA1 — HV rail monitor (10MΩ/50kΩ divider)
 *   - USART1:  Debug UART (PB6 TX, PB7 RX), 115200 baud
 *   - GPIO:    PA15 LED_STAT, PB5 CAN_STB
 *
 * HV circuit:
 *   MPSA42 base ← TIM1 CH1 PWM via 10kΩ base resistor
 *   MPSA42 collector → 1mH inductor → 5V
 *   Flyback: inductor/collector junction → UF4007 → C_HV (470pF 630V) → GND
 *   SBM-21 anode ← 400V rail via 10MΩ quench resistor
 *   SBM-21 cathode → GND
 *   Pulse: anode → 100pF 630V → comparator IN+ → TIM2 CH1 input capture
 *
 * Pulse counting:
 *   TIM2 input capture logs timestamp of every Geiger pulse
 *   Individual timestamps sent over CAN — MCU board integrates to CPM
 *   Count rate also computed locally and sent every second
 */

#include "main.h"
#include "can_ids.h"
#include "flight_state.h"
#include "hv.h"
#include <stdio.h>
#include <string.h>

/* Peripheral handles */
FDCAN_HandleTypeDef  hfdcan1;
TIM_HandleTypeDef    htim1;
TIM_HandleTypeDef    htim2;
ADC_HandleTypeDef    hadc1;
UART_HandleTypeDef   huart1;

/* CAN receive */
FDCAN_RxHeaderTypeDef rx_header;
uint8_t rx_data[64];

/* Flight state — synced from MCU board */
volatile FlightState_t flight_state = STATE_GROUND;

/* Pulse ring buffer — stores timestamps of recent pulses */
#define PULSE_BUF_SIZE  64
volatile uint32_t pulse_timestamps[PULSE_BUF_SIZE];
volatile uint8_t  pulse_head = 0;
volatile uint8_t  pulse_tail = 0;
volatile uint32_t total_pulse_count = 0;

/* Forward declarations */
static void SystemClock_Config(void);
static void MX_GPIO_Init(void);
static void MX_FDCAN1_Init(void);
static void MX_TIM1_Init(void);
static void MX_TIM2_Init(void);
static void MX_ADC1_Init(void);
static void MX_USART1_Init(void);
static void CAN_FilterConfig(void);
static void Process_CAN_Message(void);
static void Send_Pulse(uint32_t timestamp_ms);
static void Send_Count_Rate(void);
static void Send_HV_Status(void);
static uint32_t Compute_CPM(void);

/* Printf to UART */
int __io_putchar(int ch) {
    HAL_UART_Transmit(&huart1, (uint8_t*)&ch, 1, HAL_MAX_DELAY);
    return ch;
}

int main(void) {
    HAL_Init();
    SystemClock_Config();

    MX_GPIO_Init();
    MX_USART1_Init();

    printf("\r\n=== Geiger Board Firmware v0.1 ===\r\n");
    printf("STM32G0B1CCT6 | End-of-bus CAN termination fitted\r\n");

    MX_ADC1_Init();
    MX_TIM1_Init();
    MX_TIM2_Init();
    MX_FDCAN1_Init();
    CAN_FilterConfig();

    /* Init HV boost */
    HV_Init(&htim1);
    printf("[HV] Boost converter init\r\n");

    /* Start CAN */
    if (HAL_FDCAN_Start(&hfdcan1) != HAL_OK) {
        printf("[ERROR] CAN start failed\r\n");
        Error_Handler();
    }
    if (HAL_FDCAN_ActivateNotification(&hfdcan1,
        FDCAN_IT_RX_FIFO0_NEW_MESSAGE, 0) != HAL_OK)
        Error_Handler();
    printf("[OK] CAN-FD started\r\n");

    /* Start HV boost */
    HV_Start(&htim1);
    printf("[HV] Boost started — waiting for rail to stabilise\r\n");
    HAL_Delay(500); /* Allow HV rail to charge */

    /* Check HV rail */
    uint32_t hv_mv = HV_ReadRailMV(&hadc1);
    printf("[HV] Rail voltage: %lumV (target ~400000mV)\r\n",
           (unsigned long)hv_mv);
    if (hv_mv < 300000 || hv_mv > 500000)
        printf("[WARN] HV rail out of expected range\r\n");
    else
        printf("[OK] HV rail nominal\r\n");

    /* Start pulse input capture */
    HAL_TIM_IC_Start_IT(&htim2, TIM_CHANNEL_1);
    printf("[OK] Pulse capture started\r\n");

    printf("[OK] Geiger board init complete\r\n");

    uint32_t last_count_tick  = 0;
    uint32_t last_hv_tick     = 0;
    uint32_t last_status_tick = 0;
    uint32_t last_led_tick    = 0;
    uint8_t  led_state        = 0;

    while (1) {
        uint32_t now = HAL_GetTick();

        /* Process CAN — state sync from MCU board */
        if (HAL_FDCAN_GetRxFifoFillLevel(&hfdcan1, FDCAN_RX_FIFO0) > 0)
            Process_CAN_Message();

        /* Drain pulse buffer — send each pulse over CAN */
        while (pulse_head != pulse_tail) {
            uint32_t ts = pulse_timestamps[pulse_tail];
            pulse_tail = (pulse_tail + 1) % PULSE_BUF_SIZE;
            Send_Pulse(ts);
        }

        /* Send count rate every 1 second */
        if (now - last_count_tick >= 1000) {
            last_count_tick = now;
            Send_Count_Rate();
        }

        /* Send HV status every 5 seconds */
        if (now - last_hv_tick >= 5000) {
            last_hv_tick = now;
            Send_HV_Status();
        }

        /* Debug status every 10 seconds */
        if (now - last_status_tick >= 10000) {
            last_status_tick = now;
            uint32_t cpm = Compute_CPM();
            uint32_t hv  = HV_ReadRailMV(&hadc1);
            printf("[STATUS] State: %s | CPM: %lu | HV: %lumV | Total: %lu\r\n",
                Flight_State_Name(flight_state),
                (unsigned long)cpm,
                (unsigned long)hv,
                (unsigned long)total_pulse_count);
        }

        /* LED blink rate varies with count rate
         * Ground: 1Hz slow blink
         * In flight: faster blink proportional to count rate */
        uint32_t blink_interval = (flight_state == STATE_GROUND) ? 1000 : 200;
        if (now - last_led_tick >= blink_interval) {
            last_led_tick = now;
            led_state = !led_state;
            HAL_GPIO_WritePin(LED_STAT_GPIO_Port, LED_STAT_Pin,
                led_state ? GPIO_PIN_SET : GPIO_PIN_RESET);
        }
    }
}

/* ── TIM2 input capture interrupt — fires on every Geiger pulse ── */
void HAL_TIM_IC_CaptureCallback(TIM_HandleTypeDef *htim) {
    if (htim->Instance != TIM2) return;

    uint32_t ts = HAL_GetTick();

    /* Store in ring buffer */
    uint8_t next_head = (pulse_head + 1) % PULSE_BUF_SIZE;
    if (next_head != pulse_tail) { /* Buffer not full */
        pulse_timestamps[pulse_head] = ts;
        pulse_head = next_head;
    }
    total_pulse_count++;

    /* Quick LED flash on pulse — toggle briefly */
    HAL_GPIO_TogglePin(LED_STAT_GPIO_Port, LED_STAT_Pin);
}

/* ── CAN helpers ─────────────────────────────────────────────── */

static void Process_CAN_Message(void) {
    if (HAL_FDCAN_GetRxMessage(&hfdcan1, FDCAN_RX_FIFO0,
        &rx_header, rx_data) != HAL_OK)
        return;

    switch (rx_header.Identifier) {
        case CAN_ID_STATE_CHANGE:
            flight_state = (FlightState_t)rx_data[1];
            printf("[CAN] State -> %s\r\n",
                Flight_State_Name(flight_state));
            break;
        default:
            break;
    }
}

static void Send_Pulse(uint32_t timestamp_ms) {
    FDCAN_TxHeaderTypeDef tx = {0};
    tx.Identifier    = CAN_ID_GEIGER_PULSE;
    tx.IdType        = FDCAN_STANDARD_ID;
    tx.TxFrameType   = FDCAN_DATA_FRAME;
    tx.DataLength    = FDCAN_DLC_BYTES_4;
    tx.BitRateSwitch = FDCAN_BRS_ON;
    tx.FDFormat      = FDCAN_FD_CAN;

    uint8_t buf[4];
    buf[0] = (timestamp_ms >> 24) & 0xFF;
    buf[1] = (timestamp_ms >> 16) & 0xFF;
    buf[2] = (timestamp_ms >> 8)  & 0xFF;
    buf[3] = (timestamp_ms)       & 0xFF;

    HAL_FDCAN_AddMessageToTxFifoQ(&hfdcan1, &tx, buf);
}

static void Send_Count_Rate(void) {
    uint32_t cpm = Compute_CPM();

    typedef struct __attribute__((packed)) {
        uint32_t timestamp_ms;
        uint32_t cpm;
    } CountPacket_t;

    CountPacket_t pkt = {
        .timestamp_ms = HAL_GetTick(),
        .cpm          = cpm,
    };

    FDCAN_TxHeaderTypeDef tx = {0};
    tx.Identifier    = CAN_ID_GEIGER_COUNT;
    tx.IdType        = FDCAN_STANDARD_ID;
    tx.TxFrameType   = FDCAN_DATA_FRAME;
    tx.DataLength    = FDCAN_DLC_BYTES_8;
    tx.BitRateSwitch = FDCAN_BRS_ON;
    tx.FDFormat      = FDCAN_FD_CAN;
    HAL_FDCAN_AddMessageToTxFifoQ(&hfdcan1, &tx, (uint8_t*)&pkt);
}

static void Send_HV_Status(void) {
    uint32_t hv_mv = HV_ReadRailMV(&hadc1);

    FDCAN_TxHeaderTypeDef tx = {0};
    tx.Identifier    = CAN_ID_GEIGER_HV;
    tx.IdType        = FDCAN_STANDARD_ID;
    tx.TxFrameType   = FDCAN_DATA_FRAME;
    tx.DataLength    = FDCAN_DLC_BYTES_4;
    tx.BitRateSwitch = FDCAN_BRS_ON;
    tx.FDFormat      = FDCAN_FD_CAN;

    uint8_t buf[4];
    buf[0] = (hv_mv >> 24) & 0xFF;
    buf[1] = (hv_mv >> 16) & 0xFF;
    buf[2] = (hv_mv >> 8)  & 0xFF;
    buf[3] = (hv_mv)       & 0xFF;

    HAL_FDCAN_AddMessageToTxFifoQ(&hfdcan1, &tx, buf);
}

static uint32_t Compute_CPM(void) {
    /* Count pulses in the last 60 seconds from ring buffer timestamps
     * Simple approach: count entries within last 60000ms */
    uint32_t now = HAL_GetTick();
    uint32_t count = 0;
    uint8_t i = pulse_tail;
    while (i != pulse_head) {
        if ((now - pulse_timestamps[i]) <= 60000)
            count++;
        i = (i + 1) % PULSE_BUF_SIZE;
    }
    /* Scale to CPM if less than 60 seconds have elapsed */
    if (now < 60000 && now > 0)
        count = count * 60000 / now;
    return count;
}

/* ── Peripheral init ─────────────────────────────────────────── */

static void SystemClock_Config(void) {
    RCC_OscInitTypeDef RCC_OscInitStruct = {0};
    RCC_ClkInitTypeDef RCC_ClkInitStruct = {0};

    RCC_OscInitStruct.OscillatorType = RCC_OSCILLATORTYPE_HSE;
    RCC_OscInitStruct.HSEState       = RCC_HSE_ON;
    RCC_OscInitStruct.PLL.PLLState   = RCC_PLL_ON;
    RCC_OscInitStruct.PLL.PLLSource  = RCC_PLLSOURCE_HSE;
    RCC_OscInitStruct.PLL.PLLM       = RCC_PLLM_DIV1;
    RCC_OscInitStruct.PLL.PLLN       = 8;
    RCC_OscInitStruct.PLL.PLLP       = RCC_PLLP_DIV2;
    RCC_OscInitStruct.PLL.PLLQ       = RCC_PLLQ_DIV2;
    RCC_OscInitStruct.PLL.PLLR       = RCC_PLLR_DIV2;
    if (HAL_RCC_OscConfig(&RCC_OscInitStruct) != HAL_OK) Error_Handler();

    RCC_ClkInitStruct.ClockType      = RCC_CLOCKTYPE_HCLK | RCC_CLOCKTYPE_SYSCLK
                                     | RCC_CLOCKTYPE_PCLK1;
    RCC_ClkInitStruct.SYSCLKSource   = RCC_SYSCLKSOURCE_PLLCLK;
    RCC_ClkInitStruct.AHBCLKDivider  = RCC_SYSCLK_DIV1;
    RCC_ClkInitStruct.APB1CLKDivider = RCC_HCLK_DIV1;
    if (HAL_RCC_ClockConfig(&RCC_ClkInitStruct, FLASH_LATENCY_2) != HAL_OK)
        Error_Handler();
}

static void MX_FDCAN1_Init(void) {
    hfdcan1.Instance                  = FDCAN1;
    hfdcan1.Init.ClockDivider         = FDCAN_CLOCK_DIV1;
    hfdcan1.Init.FrameFormat          = FDCAN_FRAME_FD_BRS;
    hfdcan1.Init.Mode                 = FDCAN_MODE_NORMAL;
    hfdcan1.Init.AutoRetransmission   = ENABLE;
    hfdcan1.Init.TransmitPause        = DISABLE;
    hfdcan1.Init.ProtocolException    = ENABLE;
    hfdcan1.Init.NominalPrescaler     = 8;
    hfdcan1.Init.NominalSyncJumpWidth = 4;
    hfdcan1.Init.NominalTimeSeg1      = 11;
    hfdcan1.Init.NominalTimeSeg2      = 4;
    hfdcan1.Init.DataPrescaler        = 2;
    hfdcan1.Init.DataSyncJumpWidth    = 4;
    hfdcan1.Init.DataTimeSeg1         = 11;
    hfdcan1.Init.DataTimeSeg2         = 4;
    hfdcan1.Init.StdFiltersNbr        = 8;
    hfdcan1.Init.ExtFiltersNbr        = 0;
    hfdcan1.Init.TxFifoQueueMode      = FDCAN_TX_FIFO_OPERATION;
    if (HAL_FDCAN_Init(&hfdcan1) != HAL_OK) Error_Handler();
}

static void CAN_FilterConfig(void) {
    FDCAN_FilterTypeDef filter = {0};
    filter.IdType       = FDCAN_STANDARD_ID;
    filter.FilterIndex  = 0;
    filter.FilterType   = FDCAN_FILTER_RANGE;
    filter.FilterConfig = FDCAN_FILTER_TO_RXFIFO0;
    filter.FilterID1    = 0x000;
    filter.FilterID2    = 0x7FF;
    if (HAL_FDCAN_ConfigFilter(&hfdcan1, &filter) != HAL_OK) Error_Handler();
    HAL_FDCAN_ConfigGlobalFilter(&hfdcan1,
        FDCAN_REJECT, FDCAN_REJECT,
        FDCAN_FILTER_REMOTE, FDCAN_FILTER_REMOTE);
}

static void MX_TIM1_Init(void) {
    /* TIM1 CH1 PA8 — HV boost PWM
     * 64MHz / 64 = 1MHz timer clock
     * Period = 1MHz / 30kHz = 33 → ~30.3kHz */
    TIM_OC_InitTypeDef oc = {0};
    TIM_MasterConfigTypeDef master = {0};
    TIM_BreakDeadTimeConfigTypeDef bdt = {0};

    htim1.Instance               = TIM1;
    htim1.Init.Prescaler         = 63;
    htim1.Init.CounterMode       = TIM_COUNTERMODE_UP;
    htim1.Init.Period            = 32;   /* 1MHz / 33 ≈ 30.3kHz */
    htim1.Init.ClockDivision     = TIM_CLOCKDIVISION_DIV1;
    htim1.Init.RepetitionCounter = 0;
    htim1.Init.AutoReloadPreload = TIM_AUTORELOAD_PRELOAD_ENABLE;
    if (HAL_TIM_PWM_Init(&htim1) != HAL_OK) Error_Handler();

    master.MasterOutputTrigger  = TIM_TRGO_RESET;
    master.MasterOutputTrigger2 = TIM_TRGO2_RESET;
    master.MasterSlaveMode      = TIM_MASTERSLAVEMODE_DISABLE;
    if (HAL_TIMEx_MasterConfigSynchronization(&htim1, &master) != HAL_OK)
        Error_Handler();

    oc.OCMode       = TIM_OCMODE_PWM1;
    oc.Pulse        = 16;  /* 50% duty cycle */
    oc.OCPolarity   = TIM_OCPOLARITY_HIGH;
    oc.OCNPolarity  = TIM_OCNPOLARITY_HIGH;
    oc.OCFastMode   = TIM_OCFAST_DISABLE;
    oc.OCIdleState  = TIM_OCIDLESTATE_RESET;
    oc.OCNIdleState = TIM_OCNIDLESTATE_RESET;
    if (HAL_TIM_PWM_ConfigChannel(&htim1, &oc, TIM_CHANNEL_1) != HAL_OK)
        Error_Handler();

    bdt.OffStateRunMode  = TIM_OSSR_DISABLE;
    bdt.OffStateIDLEMode = TIM_OSSI_DISABLE;
    bdt.LockLevel        = TIM_LOCKLEVEL_OFF;
    bdt.DeadTime         = 0;
    bdt.BreakState       = TIM_BREAK_DISABLE;
    bdt.BreakPolarity    = TIM_BREAKPOLARITY_HIGH;
    bdt.AutomaticOutput  = TIM_AUTOMATICOUTPUT_DISABLE;
    if (HAL_TIMEx_ConfigBreakDeadTime(&htim1, &bdt) != HAL_OK)
        Error_Handler();
}

static void MX_TIM2_Init(void) {
    /* TIM2 CH1 PA0 — input capture for Geiger pulses
     * Free-running at 1MHz for microsecond resolution timestamps */
    TIM_IC_InitTypeDef ic = {0};
    TIM_MasterConfigTypeDef master = {0};

    htim2.Instance               = TIM2;
    htim2.Init.Prescaler         = 63;       /* 64MHz / 64 = 1MHz */
    htim2.Init.CounterMode       = TIM_COUNTERMODE_UP;
    htim2.Init.Period            = 0xFFFFFFFF; /* 32-bit free running */
    htim2.Init.ClockDivision     = TIM_CLOCKDIVISION_DIV1;
    htim2.Init.AutoReloadPreload = TIM_AUTORELOAD_PRELOAD_DISABLE;
    if (HAL_TIM_IC_Init(&htim2) != HAL_OK) Error_Handler();

    master.MasterOutputTrigger = TIM_TRGO_RESET;
    master.MasterSlaveMode     = TIM_MASTERSLAVEMODE_DISABLE;
    if (HAL_TIMEx_MasterConfigSynchronization(&htim2, &master) != HAL_OK)
        Error_Handler();

    ic.ICPolarity  = TIM_ICPOLARITY_RISING;
    ic.ICSelection = TIM_ICSELECTION_DIRECTTI;
    ic.ICPrescaler = TIM_ICPSC_DIV1;
    ic.ICFilter    = 0x08; /* Some input filtering to debounce */
    if (HAL_TIM_IC_ConfigChannel(&htim2, &ic, TIM_CHANNEL_1) != HAL_OK)
        Error_Handler();
}

static void MX_ADC1_Init(void) {
    ADC_ChannelConfTypeDef chan = {0};

    hadc1.Instance                   = ADC1;
    hadc1.Init.ClockPrescaler        = ADC_CLOCK_SYNC_PCLK_DIV4;
    hadc1.Init.Resolution            = ADC_RESOLUTION_12B;
    hadc1.Init.DataAlign             = ADC_DATAALIGN_RIGHT;
    hadc1.Init.ScanConvMode          = ADC_SCAN_DISABLE;
    hadc1.Init.EOCSelection          = ADC_EOC_SINGLE_CONV;
    hadc1.Init.LowPowerAutoWait      = DISABLE;
    hadc1.Init.ContinuousConvMode    = DISABLE;
    hadc1.Init.NbrOfConversion       = 1;
    hadc1.Init.DiscontinuousConvMode = DISABLE;
    hadc1.Init.ExternalTrigConv      = ADC_SOFTWARE_START;
    hadc1.Init.ExternalTrigConvEdge  = ADC_EXTERNALTRIGCONVEDGE_NONE;
    hadc1.Init.DMAContinuousRequests = DISABLE;
    hadc1.Init.Overrun               = ADC_OVR_DATA_PRESERVED;
    hadc1.Init.OversamplingMode      = ENABLE;
    hadc1.Init.Oversampling.Ratio                 = ADC_OVERSAMPLING_RATIO_16;
    hadc1.Init.Oversampling.RightBitShift         = ADC_RIGHTBITSHIFT_4;
    hadc1.Init.Oversampling.TriggeredMode         = ADC_TRIGGEREDMODE_SINGLE_TRIGGER;
    hadc1.Init.Oversampling.OversamplingStopReset = ADC_REGOVERSAMPLING_CONTINUED_MODE;
    if (HAL_ADC_Init(&hadc1) != HAL_OK) Error_Handler();

    chan.Channel      = ADC_CHANNEL_1; /* PA1 — HV monitor */
    chan.Rank         = ADC_REGULAR_RANK_1;
    chan.SamplingTime = ADC_SAMPLINGTIME_COMMON_1;
    if (HAL_ADC_ConfigChannel(&hadc1, &chan) != HAL_OK) Error_Handler();

    HAL_ADCEx_Calibration_Start(&hadc1);
}

static void MX_USART1_Init(void) {
    huart1.Instance          = USART1;
    huart1.Init.BaudRate     = 115200;
    huart1.Init.WordLength   = UART_WORDLENGTH_8B;
    huart1.Init.StopBits     = UART_STOPBITS_1;
    huart1.Init.Parity       = UART_PARITY_NONE;
    huart1.Init.Mode         = UART_MODE_TX_RX;
    huart1.Init.HwFlowCtl    = UART_HWCONTROL_NONE;
    huart1.Init.OverSampling = UART_OVERSAMPLING_16;
    if (HAL_UART_Init(&huart1) != HAL_OK) Error_Handler();
}

static void MX_GPIO_Init(void) {
    GPIO_InitTypeDef GPIO_InitStruct = {0};

    __HAL_RCC_GPIOA_CLK_ENABLE();
    __HAL_RCC_GPIOB_CLK_ENABLE();

    /* LED_STAT — PA15 */
    HAL_GPIO_WritePin(LED_STAT_GPIO_Port, LED_STAT_Pin, GPIO_PIN_RESET);
    GPIO_InitStruct.Pin   = LED_STAT_Pin;
    GPIO_InitStruct.Mode  = GPIO_MODE_OUTPUT_PP;
    GPIO_InitStruct.Pull  = GPIO_NOPULL;
    GPIO_InitStruct.Speed = GPIO_SPEED_FREQ_LOW;
    HAL_GPIO_Init(LED_STAT_GPIO_Port, &GPIO_InitStruct);

    /* CAN_STB — PB5, drive low */
    HAL_GPIO_WritePin(CAN_STB_GPIO_Port, CAN_STB_Pin, GPIO_PIN_RESET);
    GPIO_InitStruct.Pin   = CAN_STB_Pin;
    GPIO_InitStruct.Mode  = GPIO_MODE_OUTPUT_PP;
    GPIO_InitStruct.Pull  = GPIO_NOPULL;
    GPIO_InitStruct.Speed = GPIO_SPEED_FREQ_LOW;
    HAL_GPIO_Init(CAN_STB_GPIO_Port, &GPIO_InitStruct);
}

void Error_Handler(void) {
    __disable_irq();
    while (1) {
        HAL_GPIO_TogglePin(LED_STAT_GPIO_Port, LED_STAT_Pin);
        HAL_Delay(100);
    }
}

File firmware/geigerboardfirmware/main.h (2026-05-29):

/* main.h — Geiger Board */
#ifndef __MAIN_H
#define __MAIN_H

#ifdef __cplusplus
extern "C" {
#endif

#include "stm32g0xx_hal.h"

/* Pin definitions */
#define LED_STAT_Pin        GPIO_PIN_15
#define LED_STAT_GPIO_Port  GPIOA

#define CAN_STB_Pin         GPIO_PIN_5
#define CAN_STB_GPIO_Port   GPIOB

/* HV boost PWM — TIM1 CH1 PA8 */
#define HV_PWM_Pin          GPIO_PIN_8
#define HV_PWM_GPIO_Port    GPIOA

/* Geiger pulse input capture — TIM2 CH1 PA0 */
#define GEIGER_PULSE_Pin    GPIO_PIN_0
#define GEIGER_PULSE_Port   GPIOA

/* HV monitor ADC — PA1 */
#define HV_MON_Pin          GPIO_PIN_1
#define HV_MON_GPIO_Port    GPIOA

/* ADC channel */
#define HV_MON_CHANNEL      ADC_CHANNEL_1

/* HV divider scaling
 * 10MΩ top / 50kΩ bottom
 * V_adc = V_hv * 50k / (10M + 50k) = V_hv / 201
 * V_hv_mv = adc_mv * 201 */
#define HV_DIVIDER_SCALE    201

/* ADC reference */
#define ADC_VREF_MV         3300
#define ADC_RESOLUTION      4096

/* Peripheral handles */
extern FDCAN_HandleTypeDef  hfdcan1;
extern TIM_HandleTypeDef    htim1;
extern TIM_HandleTypeDef    htim2;
extern ADC_HandleTypeDef    hadc1;
extern UART_HandleTypeDef   huart1;

void Error_Handler(void);

#ifdef __cplusplus
}
#endif

#endif /* __MAIN_H */

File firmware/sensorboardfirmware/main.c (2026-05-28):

/* Sensor Board Firmware — Ring PCB B
 * STM32G0B1CCT6
 * Placeholder firmware for hardware bring-up
 *
 * Peripherals:
 *   - FDCAN1:  CAN-FD bus, 500kbps arbitration / 2Mbps data
 *   - I2C1:    Sensor bus (PB6 SCL, PB7 SDA)
 *              MS5607 @ 0x76, BMP390 @ 0x77, SHT40 @ 0x44, LSM6DSO32 @ 0x6A
 *   - ADC1:    PA0 charge HI, PA1 charge LO (LMP7721), PA2 nosecone thermistor
 *   - TIM1:    CH1 PA8 — piezo swept sine PWM
 *   - USART1:  Debug UART (PB6 TX, PB7 RX) — NOTE: shared pins with I2C1
 *              Use USART1 only before I2C1 is started, or remap to different pins
 *   - GPIO:    PA3 ADXL_INT1, PA4 LSM_INT1, PA15 LED_STAT, PB5 CAN_STB
 *
 * NOTE on USART/I2C pin conflict:
 *   PB6/PB7 are shared between USART1 and I2C1 on G0B1.
 *   In this firmware USART1 is used for early boot debug only.
 *   I2C1 takes over after sensor init. Remap USART to PA9/PA10 in CubeMX
 *   if simultaneous debug + I2C is needed.
 */

#include "main.h"
#include "can_ids.h"
#include "flight_state.h"
#include "sensors.h"
#include "charge.h"
#include "piezo.h"
#include <stdio.h>
#include <string.h>

/* Peripheral handles */
FDCAN_HandleTypeDef  hfdcan1;
I2C_HandleTypeDef    hi2c1;
ADC_HandleTypeDef    hadc1;
TIM_HandleTypeDef    htim1;
UART_HandleTypeDef   huart1;

/* CAN receive */
FDCAN_RxHeaderTypeDef rx_header;
uint8_t rx_data[64];

/* Flight state — synced from MCU board via CAN */
volatile FlightState_t flight_state = STATE_GROUND;

/* Forward declarations */
static void SystemClock_Config(void);
static void MX_GPIO_Init(void);
static void MX_FDCAN1_Init(void);
static void MX_I2C1_Init(void);
static void MX_ADC1_Init(void);
static void MX_TIM1_Init(void);
static void MX_USART1_Init(void);
static void CAN_FilterConfig(void);
static void Process_CAN_Message(void);
static void Send_Sensor_Data(void);
static void Send_Charge_Data(void);
static void Send_Thermistor_Data(void);

/* Printf to UART */
int __io_putchar(int ch) {
    HAL_UART_Transmit(&huart1, (uint8_t*)&ch, 1, HAL_MAX_DELAY);
    return ch;
}

int main(void) {
    HAL_Init();
    SystemClock_Config();

    MX_GPIO_Init();
    MX_USART1_Init();

    printf("\r\n=== Sensor Board Firmware v0.1 ===\r\n");
    printf("STM32G0B1CCT6\r\n");

    MX_I2C1_Init();
    MX_ADC1_Init();
    MX_TIM1_Init();
    MX_FDCAN1_Init();
    CAN_FilterConfig();

    /* Init sensors */
    printf("[SENSOR] Initialising sensors...\r\n");

    if (MS5607_Init(&hi2c1) != SENSOR_OK)
        printf("[WARN] MS5607 init failed\r\n");
    else
        printf("[OK] MS5607\r\n");

    if (BMP390_Init(&hi2c1) != SENSOR_OK)
        printf("[WARN] BMP390 init failed\r\n");
    else
        printf("[OK] BMP390\r\n");

    if (SHT40_Init(&hi2c1) != SENSOR_OK)
        printf("[WARN] SHT40 init failed\r\n");
    else
        printf("[OK] SHT40\r\n");

    if (LSM6DSO32_Init(&hi2c1) != SENSOR_OK)
        printf("[WARN] LSM6DSO32 init failed\r\n");
    else
        printf("[OK] LSM6DSO32\r\n");

    /* Init charge frontend */
    Charge_Init(&hadc1);
    printf("[OK] Charge frontend\r\n");

    /* Start CAN */
    if (HAL_FDCAN_Start(&hfdcan1) != HAL_OK) {
        printf("[ERROR] CAN start failed\r\n");
        Error_Handler();
    }
    if (HAL_FDCAN_ActivateNotification(&hfdcan1,
        FDCAN_IT_RX_FIFO0_NEW_MESSAGE, 0) != HAL_OK)
        Error_Handler();
    printf("[OK] CAN-FD started\r\n");

    /* Piezo init — don't start sweep yet */
    Piezo_Init(&htim1);
    printf("[OK] Piezo driver ready\r\n");

    printf("[OK] Sensor board init complete\r\n");

    /* Timing */
    uint32_t last_baro_tick    = 0;
    uint32_t last_imu_tick     = 0;
    uint32_t last_charge_tick  = 0;
    uint32_t last_env_tick     = 0;
    uint32_t last_therm_tick   = 0;
    uint32_t last_status_tick  = 0;

    while (1) {
        uint32_t now = HAL_GetTick();

        /* Process incoming CAN — mainly state change from MCU board */
        if (HAL_FDCAN_GetRxFifoFillLevel(&hfdcan1, FDCAN_RX_FIFO0) > 0)
            Process_CAN_Message();

        /* Barometric — 10Hz */
        if (now - last_baro_tick >= 100) {
            last_baro_tick = now;
            Send_Sensor_Data();
        }

        /* IMU — rate depends on flight state */
        uint32_t imu_rate = (flight_state == STATE_BOOST ||
                             flight_state == STATE_COAST) ? 1 : 10;
        if (now - last_imu_tick >= imu_rate) {
            last_imu_tick = now;
            Sensors_Send_IMU(&hfdcan1, &hi2c1, flight_state);
        }

        /* Charge measurement — 100Hz */
        if (now - last_charge_tick >= 10) {
            last_charge_tick = now;
            Send_Charge_Data();
        }

        /* Humidity + temp — 1Hz */
        if (now - last_env_tick >= 1000) {
            last_env_tick = now;
            Sensors_Send_Env(&hfdcan1, &hi2c1);
        }

        /* Nosecone thermistor — 2Hz */
        if (now - last_therm_tick >= 500) {
            last_therm_tick = now;
            Send_Thermistor_Data();
        }

        /* Status print — 5s */
        if (now - last_status_tick >= 5000) {
            last_status_tick = now;
            printf("[STATUS] State: %s | tick: %lu\r\n",
                Flight_State_Name(flight_state), now);
        }

        /* Piezo sweep — only during descent */
        if (flight_state == STATE_DESCENT)
            Piezo_RunSweep(&htim1, &hfdcan1);
    }
}

static void Process_CAN_Message(void) {
    if (HAL_FDCAN_GetRxMessage(&hfdcan1, FDCAN_RX_FIFO0,
        &rx_header, rx_data) != HAL_OK)
        return;

    switch (rx_header.Identifier) {

        case CAN_ID_STATE_CHANGE:
            /* MCU board broadcasting new flight state */
            flight_state = (FlightState_t)rx_data[1];
            printf("[CAN] State -> %s\r\n",
                Flight_State_Name(flight_state));

            /* Start/stop piezo based on state */
            if (flight_state == STATE_DESCENT)
                Piezo_Start(&htim1);
            else
                Piezo_Stop(&htim1);
            break;

        default:
            break;
    }
}

static void Send_Sensor_Data(void) {
    typedef struct __attribute__((packed)) {
        int32_t  pressure_pa;     /* Pascal * 100 fixed point */
        int32_t  altitude_mm;     /* mm above sea level */
        int32_t  temperature_mc;  /* millidegrees C */
    } BaroPacket_t;

    BaroPacket_t pkt = {0};

    /* Read MS5607 */
    MS5607_Data_t ms_data;
    if (MS5607_Read(&hi2c1, &ms_data) == SENSOR_OK) {
        pkt.pressure_pa    = ms_data.pressure_pa;
        pkt.altitude_mm    = ms_data.altitude_mm;
        pkt.temperature_mc = ms_data.temperature_mc;
    }

    FDCAN_TxHeaderTypeDef tx = {0};
    tx.Identifier    = CAN_ID_SENSOR_BARO;
    tx.IdType        = FDCAN_STANDARD_ID;
    tx.TxFrameType   = FDCAN_DATA_FRAME;
    tx.DataLength    = FDCAN_DLC_BYTES_12;
    tx.BitRateSwitch = FDCAN_BRS_ON;
    tx.FDFormat      = FDCAN_FD_CAN;
    HAL_FDCAN_AddMessageToTxFifoQ(&hfdcan1, &tx, (uint8_t*)&pkt);
}
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

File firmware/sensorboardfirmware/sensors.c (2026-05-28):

/* sensors.c — I2C sensor driver implementations
 * Placeholder/bring-up level — minimal error handling
 * TODO: add full calibration compensation for MS5607 and BMP390
 */

#include "sensors.h"
#include <string.h>
#include <stdio.h>

/* ── MS5607 ─────────────────────────────────────────────────── */

static MS5607_Data_t ms5607_ctx = {0};

static uint8_t MS5607_SendCmd(I2C_HandleTypeDef *hi2c, uint8_t cmd) {
    return HAL_I2C_Master_Transmit(hi2c, MS5607_ADDR, &cmd, 1, 100);
}

static uint32_t MS5607_ReadADC(I2C_HandleTypeDef *hi2c) {
    uint8_t buf[3] = {0};
    uint8_t cmd = MS5607_CMD_READ_ADC;
    HAL_I2C_Master_Transmit(hi2c, MS5607_ADDR, &cmd, 1, 100);
    HAL_I2C_Master_Receive(hi2c, MS5607_ADDR, buf, 3, 100);
    return ((uint32_t)buf[0] << 16) | ((uint32_t)buf[1] << 8) | buf[2];
}

uint8_t MS5607_Init(I2C_HandleTypeDef *hi2c) {
    /* Reset */
    if (MS5607_SendCmd(hi2c, MS5607_CMD_RESET) != HAL_OK)
        return SENSOR_ERROR;
    HAL_Delay(10);

    /* Read PROM calibration coefficients C1-C6 */
    for (int i = 1; i <= 6; i++) {
        uint8_t cmd = MS5607_CMD_READ_PROM | (i << 1);
        uint8_t buf[2] = {0};
        if (HAL_I2C_Master_Transmit(hi2c, MS5607_ADDR, &cmd, 1, 100) != HAL_OK)
            return SENSOR_ERROR;
        if (HAL_I2C_Master_Receive(hi2c, MS5607_ADDR, buf, 2, 100) != HAL_OK)
            return SENSOR_ERROR;
        ms5607_ctx.C[i] = ((uint16_t)buf[0] << 8) | buf[1];
        printf("[MS5607] C%d = %u\r\n", i, ms5607_ctx.C[i]);
    }
    return SENSOR_OK;
}

uint8_t MS5607_Read(I2C_HandleTypeDef *hi2c, MS5607_Data_t *data) {
    /* Convert pressure */
    MS5607_SendCmd(hi2c, MS5607_CMD_CONVERT_D1);
    HAL_Delay(10);
    uint32_t D1 = MS5607_ReadADC(hi2c);

    /* Convert temperature */
    MS5607_SendCmd(hi2c, MS5607_CMD_CONVERT_D2);
    HAL_Delay(10);
    uint32_t D2 = MS5607_ReadADC(hi2c);

    /* Calculate temperature — MS5607 datasheet equations */
    int32_t dT   = (int32_t)D2 - ((int32_t)ms5607_ctx.C[5] << 8);
    int32_t TEMP = 2000 + ((int64_t)dT * ms5607_ctx.C[6] >> 23);

    /* Calculate pressure */
    int64_t OFF  = ((int64_t)ms5607_ctx.C[2] << 17)
                 + (((int64_t)ms5607_ctx.C[4] * dT) >> 6);
    int64_t SENS = ((int64_t)ms5607_ctx.C[1] << 16)
                 + (((int64_t)ms5607_ctx.C[3] * dT) >> 7);
    int32_t P    = (int32_t)(((D1 * SENS >> 21) - OFF) >> 15);

    data->temperature_mc = TEMP * 10;  /* Convert 0.01C to mC */
    data->pressure_pa    = P;
    data->altitude_mm    = MS5607_PressureToAltitude(P);

    memcpy(&ms5607_ctx, data, sizeof(MS5607_Data_t));
    return SENSOR_OK;
}

int32_t MS5607_PressureToAltitude(int32_t pressure_pa) {
    /* International Standard Atmosphere approximation
     * Valid to ~11km. TODO: extend for stratosphere.
     * h = 44330 * (1 - (P/P0)^(1/5.255)) metres
     * Simplified integer version — returns mm */
    if (pressure_pa <= 0) return 0;
    /* Placeholder: linear approximation near sea level */
    /* Replace with proper ISA calculation in firmware dev */
    int32_t delta = 101325 - pressure_pa;
    return (int32_t)((int64_t)delta * 8300 / 1000); /* ~8.3m per 1hPa near SL */
}

/* ── BMP390 ─────────────────────────────────────────────────── */

static uint8_t BMP390_ReadReg(I2C_HandleTypeDef *hi2c,
                               uint8_t reg, uint8_t *buf, uint8_t len) {
    if (HAL_I2C_Master_Transmit(hi2c, BMP390_ADDR, &reg, 1, 100) != HAL_OK)
        return SENSOR_ERROR;
    if (HAL_I2C_Master_Receive(hi2c, BMP390_ADDR, buf, len, 100) != HAL_OK)
        return SENSOR_ERROR;
    return SENSOR_OK;
}

static uint8_t BMP390_WriteReg(I2C_HandleTypeDef *hi2c,
                                uint8_t reg, uint8_t val) {
    uint8_t buf[2] = {reg, val};
    return HAL_I2C_Master_Transmit(hi2c, BMP390_ADDR, buf, 2, 100);
}

uint8_t BMP390_Init(I2C_HandleTypeDef *hi2c) {
    uint8_t chip_id = 0;
    if (BMP390_ReadReg(hi2c, BMP390_REG_CHIP_ID, &chip_id, 1) != SENSOR_OK)
        return SENSOR_ERROR;
    if (chip_id != BMP390_CHIP_ID) {
        printf("[BMP390] Bad chip ID: 0x%02X\r\n", chip_id);
        return SENSOR_ERROR;
    }

    /* Enable pressure and temperature, normal mode */
    BMP390_WriteReg(hi2c, BMP390_REG_PWR_CTRL, 0x33);
    /* OSR: pressure x8, temperature x1 */
    BMP390_WriteReg(hi2c, BMP390_REG_OSR, 0x03);
    HAL_Delay(10);
    return SENSOR_OK;
}

uint8_t BMP390_Read(I2C_HandleTypeDef *hi2c, BMP390_Data_t *data) {
    uint8_t buf[6] = {0};
    if (BMP390_ReadReg(hi2c, BMP390_REG_DATA_0, buf, 6) != SENSOR_OK)
        return SENSOR_ERROR;

    /* Raw pressure: 24-bit */
    uint32_t raw_p = (uint32_t)buf[0] | ((uint32_t)buf[1] << 8)
                   | ((uint32_t)buf[2] << 16);
    /* Raw temperature: 24-bit */
    uint32_t raw_t = (uint32_t)buf[3] | ((uint32_t)buf[4] << 8)
                   | ((uint32_t)buf[5] << 16);

    /* TODO: apply BMP390 compensation formulas from datasheet
     * Placeholder: simple scaling for bring-up */
    data->pressure_pa    = (int32_t)(raw_p / 256);
    data->temperature_mc = (int32_t)(raw_t / 100) - 273150; /* rough K to mC */

    return SENSOR_OK;
}

/* ── SHT40 ──────────────────────────────────────────────────── */

uint8_t SHT40_Init(I2C_HandleTypeDef *hi2c) {
    /* SHT40 needs no init — just verify it responds */
    uint8_t cmd = SHT40_CMD_MEASURE_HI;
    if (HAL_I2C_Master_Transmit(hi2c, SHT40_ADDR, &cmd, 1, 100) != HAL_OK)
        return SENSOR_ERROR;
    HAL_Delay(10);
    uint8_t buf[6] = {0};
    if (HAL_I2C_Master_Receive(hi2c, SHT40_ADDR, buf, 6, 100) != HAL_OK)
        return SENSOR_ERROR;
    return SENSOR_OK;
}
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

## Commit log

2026-05-13 Optimize camera PCB for cost and layout
    Revamped camera PCB design for cost optimization by switching to single-sided components and reducing layers from 6 to 4. Updated all components to basic options from JLCPCB to minimize expenses.
2026-05-13 Revise journal entries for CAD and sensor board updates
    Updated journal entries with new CAD work and sensor board revisions, including detailed descriptions and images of the instrumentation stack and AV bulkhead design.
2026-05-14 Document progress on PCB fixes and CAD work
    Added detailed entries about PCB fixes, component changes, and CAD work. Included images and reflections on project progress.
2026-05-15 Update PCB entry in JOURNAL.md
    Removed HTML image tag and updated entry title.
2026-05-15 Update JOURNAL.md with CAD design progress
    Document progress on CAD design for rocket components including motor coupling, fin can, and nozzle architecture. Outline remaining tasks for completion.
2026-05-18 Update JOURNAL with AV Bay design and assembly details
    Documented the final design and assembly details for the AV Bay, including components, assembly instructions, and performance metrics.
2026-05-19 Clarify description of atmospheric charge measurement
    Reworded the explanation of Experiment 2 for clarity.
2026-05-19 Update JOURNAL.md with recent project progress
    Added detailed journal entries about BOM, renders, and README updates.
2026-05-28 Add initial content to wiringdiagrams readme
2026-05-28 Update README with BOM link and CSV attachment
    Added link to BOM and mention of CSV attachment.
2026-05-28 Add initial readme for PCB files
2026-05-28 Create sensorboardfirmware
2026-05-28 Update BOM TTMT.csv
    [BOM TTMT.csv]
2026-05-29 Rename wiringdiagrams and pcbphotos/cameraboard/readme.md to wiringdiagrams and pcbphotos/cameraboard.md
2026-05-29 Add sensorPCB_PHOTOS.md with PCB images
    Add images for sensor PCB in markdown format
2026-05-29 Rename wiringdiagrams and pcbphotos/cameraPCB_PHOTOS.md to wiringdiagrams and pcbphotos/pcbphotos/cameraPCB_PHOTOS.md
2026-05-29 Rename wiringdiagrams and pcbphotos/flexcablePCB_PHOTOS.md to wiringdiagrams and pcbphotos/pcbphotos/flexcablePCB_PHOTOS.md
2026-05-29 Rename wiringdiagrams and pcbphotos/geigerPCB_PHOTOS.md to wiringdiagrams and pcbphotos/pcbphotos/geigerPCB_PHOTOS.md
2026-05-29 Rename wiringdiagrams and pcbphotos/mcuPCB_PHOTOS.md to wiringdiagrams and pcbphotos/pcbphotos/mcuPCB_PHOTOS.md
2026-05-29 Rename wiringdiagrams and pcbphotos/sensorPCB_PHOTOS.md to wiringdiagrams and pcbphotos/pcbphotos/sensorPCB_PHOTOS.md
2026-05-29 Rename BOM TTMT.csv to BOM.csv
    [BOM.csv]
2026-06-03 add cad to lfs
    [fullupTTMT.f3z, fullupTTMT.step]
2026-06-03 Add BOM section to README
    Added a Bill of Materials (BOM) section detailing items, quantities, costs, sources, and purposes for the project.
